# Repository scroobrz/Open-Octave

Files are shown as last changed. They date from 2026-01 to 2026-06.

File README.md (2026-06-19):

<div align="center">
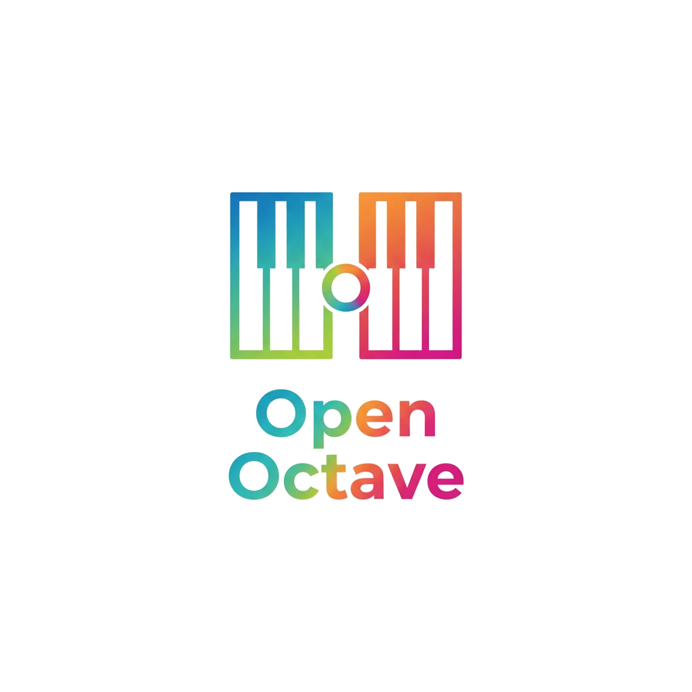
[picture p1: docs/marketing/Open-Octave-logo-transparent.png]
Open Octave Logo
  
</div>

# Open Octave

## Project Overview
**Open Octave** is a modular, robotically enhanced educational piano keyboard system designed to make early-stage piano education more accessible and engaging in the classroom. The physical system consists of connectable keyboard modules controlled by our firmware. The system also provides a teacher-facing frontend which allows them to control the keyboard modules remotely, and a proxy server for software-firmware communication.

**Open Octave's** robotic features, such as light-up keys and a self-playing mechanism, enable unique learning modes aimed at aiding the retention of melodic piano sequences for young learners. Its modularity also encourages less advanced learners to become familiar with the mechanics of piano playing on smaller keyboard modules without being overwhelmed by a full 88-key smart keyboard with all bells and whistles.

**Open Octave** began as an undergraduate robotics project at The University of Edinburgh, and has now been made open course for further development.

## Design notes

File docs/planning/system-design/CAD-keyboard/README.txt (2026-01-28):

MIDI keyboard keys - Casio CTK3000 by Dark_Jumpy on Thingiverse: https://www.thingiverse.com/thing:4328527

Summary:
MIDI keyboard keys designed for Casio CTK3000 but it's possible it also fits other keyboards. If you would like to print the whole octave you have to print:-1 x holding-belt-5 x piano_black_key-2 x type1-piano-white-key-2 x type2-piano-white-key-1 x type3-piano-white-key-1 x type4-piano-white-key-1 x type5-piano-white-keyIf you would like to print the whole octave with the one full white key on any side you have to print:-1 x holding-belt-long-5 x piano_black_key-2 x type1-piano-white-key-2 x type2-piano-white-key-1 x type3-piano-white-key-1 x type4-piano-white-key-1 x type5-piano-white-key-1 x full-piano-white-keyWhen you printed your octave then you have to put your keys in they place in MIDI keyboard and glue to them a holding belt. Next, you have to make holes for the screws in the places where are holes in the MIDI keyboard in that way witch you can screw octave to the keyboard. If you would like to have a nice look of the keys I recommend print them slowly because they have thin walls.If you have any question let me know about it in the comment.

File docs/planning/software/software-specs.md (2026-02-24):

# Open Octave – Demo 2 Architecture & Integration Specification  
**(Alignment Document)**

---

# 1. Demo 2 Scope and Locked Decisions

## 1.1 Objectives

Demo 2 must deliver:

- Replacement of Demo 1 CLI with Software (Node controller + Web UI)
- Firmware-controlled Guided and Teaching logic
- USB Serial as primary communication path
- WiFi WebSocket as optional path
- Clean architecture that scales to Demo 3 (multi-module networking)
- Flexible protocol that avoids rewriting firmware later

**refer controller/server.js

---

## 1.2 Transport Decisions

### Primary (Demo 2)
- USB Serial @ 115200 baud

### Optional (Demo 2)
- ESP32 SoftAP
- WebSocket server on port 81
- Same single-character command format over both transports

### Future (Demo 3)
- Raspberry Pi hosts:
  - WebSocket server
  - SQLite database
  - WiFi Access Point
- ESP32 modules become WebSocket clients

---

# 2. Command & Protocol Architecture

## 2.1 Command Philosophy

- **Single-character commands** → button-like actions
- **Text-based structured responses** → machine-readable state and events
- Same command format across Serial and WebSocket

---

## 2.2 Idempotency Rules

| Command | Behavior |
|---|---|
| Mode change (`m`, `a`, `f`) | Idempotent. No effect if already in that mode. |
| `s` (start) | Ignored if already running. |
| `x` (stop) | Idempotent. Stops immediately. |
| Sequence select | Stops current sequence before switching. |
| Restart | Separate command if needed (not `s`). |

Stop confirmation popup is handled in the UI (default = Yes on Enter).

---

## 2.3 Machine-Readable Responses (Required)

Firmware must emit structured messages prefixed with:

- `ACK` (acknowledge)
- `STATUS`
- `EVT` (event)
- `ERR` (error)

### Examples

```
ACK mode=GUIDED
ACK start=ok seq=3
ACK stop=ok
ERR cmd=start reason=manual_mode
STATUS mode=GUIDED running=1 seq=3 step=4
EVT guided_step key=2 duration=500
EVT correct_press key=2
EVT wrong_press expected=2 got=5
EVT hold_complete key=2
EVT sequence_complete
```

Controller updates state ONLY from these structured messages.

**Backend will do the processing, and esp32 will just send the current event/ack going on

Reason: if using local mirror from microcontroller "sent", false positive communication may occur. we only know command left the controller, but not sure if esp32 received/accepted/actually changed mode. (more robust)

---

## 2.4 Status Query (Locked)

New command: `q`

Firmware response: ```STATUS mode= running=<0|1> seq= step=```

Demo 3 option (not implemented now):
- Periodic heartbeat `HB ...`

---

## 2.5 Sequence List (Machine-Readable)

New command: `L`

Response format: ```SEQ_LIST 0:PingPong|1:OdeToJoy|2:Lullaby|…```

---

# 3. Guided Mode Specification

Firmware fully owns Guided logic.

Software:
- Triggers mode
- Displays state
- Logs events
- Tracks wrong presses for future reports

---

## 3.1 Required Guided Behavior

For each step:

1. Emit: ```EVT guided_step key=K duration=D```
2. LED turns on.
3. If wrong key pressed: ```EVT wrong_press expected=K got=J```
4. On correct press: ```EVT correct_press key=K```
5. Enforce hold duration D: ```EVT hold_complete key=K```
6. Advance step.
7. On completion: ```EVT sequence_complete```

---

## 3.2 Known Limitations (To Improve)

### Repeated Notes Issue
If the same key appears consecutively:
- LED does not visually indicate new step.

Possible solutions:
- LED pulse at step start
- Require release edge before next press
- Brief LED off-on reset

### Hold Visualization
LED remains ON during hold.
Optional:
- Blink or color change when release allowed.

---

# 4. Sequence Management Plan (Two Stages)

---

# Stage 1 – Hardcoded Sequences (Demo 2 Initial)

- Sequences remain in firmware (`firmware_V4_sequences.h`)
- Controller only selects and triggers playback
- No upload protocol required
- SQLite already implemented on server for future compatibility

---

# Stage 2 – Upload Protocol + SQLite (Demo 2 Extension)

## 4.1 Sequence Upload Protocol (Locked: Option A)

Line-based text protocol using newline delimiters.

for now, choose midi files that use ONLY one octave keys to show users can upload midi files and converted into light sequences.

### Begin Upload
```U seq_id=12 name=“OdeToJoy” steps=7```

### Step Lines
```S i=0 k=1 c=00FF00 d=400
S i=1 k=1 c=00FF00 d=400
```

### End Upload
```E seq_id=12```

### Firmware Responses
ACK upload=begin seq_id=12 steps=7
ACK upload=step i=0
…
ACK upload=end seq_id=12 stored=ram
ERR upload=bad_step i=3 reason=invalid_key

---

## 4.2 Expected Upload Time

Serial throughput ≈ 11,520 bytes/sec.

Estimated upload times:

| Steps | Approx Time |
|--------|-------------|
| 16     | ~0.05 sec |
| 64     | ~0.18 sec |
| 128    | ~0.34 sec |
| 256    | ~0.68 sec |

Even with ACK responses, upload remains sub-second for normal sequence sizes.

---

## 4.3 Option B (Future Consideration Only)

Length-prefixed JSON frames.

Pros:
- Self-describing
- Structured

Cons:
- Heavier parser
- Higher firmware risk
- More memory usage

Not selected for Demo 2.

---

# 5. Server-Side Storage Decision (Locked)

We will use **SQLite starting in Demo 2 Stage 2**.

Reason:
- Simple single-file database
- Works on laptop and Raspberry Pi
- Avoids migration later
- Durable and reliable
- Industry-standard lightweight storage

---

## 5.1 SQLite Schema

### Table: sequences
- id INTEGER PRIMARY KEY
- name TEXT
- created_at TEXT
- updated_at TEXT

### Table: sequence_steps
- id INTEGER PRIMARY KEY
- sequence_id INTEGER
- step_order INTEGER
- key_index INTEGER
- color INTEGER
- duration_ms INTEGER

---

## 5.2 State Tracking Storage

- Live device state: In-memory only
- Persist sequences in SQLite
- Optionally persist:
  - Last selected sequence
  - Last known mode

Do NOT write state changes (like every step) to DB.

---

# 6. Proxy-Side State Tracking (Locked)

Old behavior:
- Controller returned `{success:true, cmd:"m"}`

New behavior:
- Controller waits for `ACK`
- Maintains local mirror:
  - mode
  - running
  - current sequence
  - step index

API returns mirror state, not just “cmd sent”.

Reason:
- Transport success ≠ firmware success
- Needed for multi-device future
- Prevents UI desync

---

# 7. MIDI Strategy

## Demo 2
- Pre-convert MIDI offline
- Hardcode sequences

## Demo 3 Direction
- Parse MIDI on server (Node.js)
- Convert to sequence steps
- Store in SQLite
- Upload using Stage 2 protocol

Library candidate:
- `@tonejs/midi`

Still required:
- Pitch mapping rules
- Tempo conversion
- Quantization
- Polyphony handling strategy

---

# 8. Firmware Responsibilities (After Review)

Firmware must add:

- ACK responses for all state-changing commands
- STATUS command (`q`)
- Machine-readable sequence list (`L`)
- Guided mode event emission
- Upload parser (Stage 2)
- Fixed-size RAM buffer for uploaded sequences
- Step validation and limits

Avoid:
- Heavy dynamic memory
- JSON parsing in firmware

---

# 9. Electronics Alignment Required

## 9.1 12-Key Scaling
- Final GPIO mapping
- LED wiring strategy (individual pins vs chained strip)
- I2C reserved pins
- Confirm pull-up strategy

## 9.2 Power
- Servo power budget
- Grounding scheme
- 3.3V logic compatibility

## 9.3 Audio
- Confirm final audio approach before implementing volume control

---

---

# 10. Additional Architectural Considerations & Constraints

This section consolidates important considerations, risks, and alignment notes that were agreed during design discussions but were not yet explicitly written into this document.

---

# 10.1 Logging, Memory Model & Safe Upload Limits 

The firmware uses structured log prefixes (`ACK`, `STATUS`, `EVT`, `ERR`) to support robust software-side state tracking.

## Logging Memory Model

- Logging macros use fixed-size stack buffers (`LOG_BUFFER_SIZE = 128`).
- No persistent log buffering is implemented.
- Logs are streamed directly to Serial and WebSocket.
- Machine-readable prefixes do **not** significantly increase RAM usage.
- Avoid heavy dynamic `String` usage inside frequent execution paths.
- No JSON parsing will be implemented in firmware.

This keeps memory deterministic and avoids heap fragmentation.

---

## Upload Memory Strategy (Safe Maximum Based on `SequenceStep` Size)

Uploaded sequences will be stored in RAM only.

No dynamic heap allocation will be used for upload storage.

Instead, firmware will use a fixed-size static buffer: ```SequenceStep uploadedSteps[MAX_UPLOADED_STEPS];```

### SequenceStep Memory Size (proposed)

```cpp
struct SequenceStep {
uint8_t keyIndex;   // 1 byte
uint32_t color;     // 4 bytes
uint16_t duration;  // 2 bytes
};
```

Estimated raw size ≈ 7 bytes  
Aligned size (typical 32-bit alignment) ≈ 8 bytes per step.

### Safe Maximum Step Count

The safe maximum will be calculated based on:

- Available free heap after firmware initialisation
- Worst-case stack usage
- Logging buffer usage
- WiFi + WebSocket memory overhead

The buffer size will be selected conservatively to:

- Avoid memory exhaustion
- Avoid heap fragmentation
- Maintain stable servo + LED timing

Example estimation (for reference only):

| Steps | Approx RAM Usage |
|---|---|
| 128 | ~1 KB |
| 256 | ~2 KB |
| 512 | ~4 KB |

Final `MAX_UPLOADED_STEPS` will be locked after measuring actual free heap on ESP32 during runtime.

---

## Firmware Constraints for Electronics Team

Electronics team should expect:

- Upload storage is RAM-only (not flash).
- Maximum uploaded sequence length is fixed and enforced.
- Oversized uploads will return: ```ERR upload=too_many_steps max=```

- No dynamic heap expansion for upload.
- Deterministic memory usage is prioritised over flexibility.

This ensures:
- Stable real-time performance.
- No unexpected servo timing jitter.
- No runtime crashes due to heap fragmentation.

---

## Design Principle 

Firmware memory usage must remain:

- Deterministic
- Bounded
- Real-time safe

Flexibility (e.g., unlimited upload length) is intentionally sacrificed to maintain system stability.

---

# 10.2 Command Design Rule (Locked Principle)

To prevent protocol drift in Demo 3:

- **Single-character commands** are reserved for button-like control actions.
- **Text-based messages** are reserved for structured data transfer (upload, state, events).

---

# 10.3 Stop Confirmation – Explicit Responsibility Split

- Firmware stops immediately upon receiving `x`. (separate command from current `stop sequence`)
- Confirmation logic is handled entirely in the UI.
- UI displays confirmation modal.
- Pressing Enter defaults to "Yes". (prevent double clicking)

Firmware might not implement delayed stop logic.

---

# 10.4 Guided Mode – Open Discussion Flags

The following items require joint firmware + UX + electronics alignment before final locking:

## Repeated Notes Handling

Problem:
- Consecutive identical key steps do not visually indicate a new required press.

Options:
- LED pulse at each new step.
- Require release edge detection before accepting next press.
- Brief LED off-on reset between steps.

---

## Hold Duration Visualization

Current:
- LED remains ON during hold.

Possible improvements:
- LED blinking while hold is active.
- LED color change when release allowed.
- Progress-style visual indicator.

Requires UX discussion.

---

# 10.5 Sequence Upload – Memory Limits & ACK Strategy

## Upload Storage Decision

- Uploaded sequences are stored in RAM only.
- Not persisted in flash.
- Maximum step limit must be defined (e.g., MAX_UPLOADED_STEPS).
- Upload exceeding limit must return: ```ERR upload=too_many_steps max=```

## ACK Strategy (Low-Risk Compromise)

To balance reliability and traffic:

- `ACK upload=begin`
- Optional periodic ACK (every N steps)
- `ACK upload=end`

Per-step ACK is allowed but increases traffic.

Serial throughput remains sub-second for normal sizes.

---

# 10.6 Database Design Assumptions

SQLite is selected starting from Demo 2 Stage 2.

## Assumptions

- Controller is the single writer.
- No concurrent external DB writers.
- Sequences are low-frequency writes.
- Runtime state (step changes) is NOT written to DB.

## Risk Control

- Use transactions when inserting sequences + steps.
- Keep live state mirror in memory.
- Persist only low-frequency configuration data.

---

# 10.7 MIDI Parsing Responsibility (Explicit Separation)

Firmware will NOT parse MIDI.

All MIDI processing will occur on the server side:

1. Parse MIDI file.
2. Convert to internal step structure.
3. Apply:
 - Pitch mapping rules.
 - Tempo conversion.
 - Quantization.
 - Polyphony strategy.
4. Store in SQLite.
5. Upload to firmware via Stage 2 protocol.

This keeps firmware lightweight and real-time safe.

---

# 10.8 Demo 3 Networking – High-Level Alignment Notes

Future architecture direction:

- One Raspberry Pi controls multiple ESP32 modules.
- Each module must have a device identifier.
- Controller must track state per device.
- Commands must be routed per module.
- Upload protocol must support device targeting.

Implication:
Protocol design today must remain extensible for device addressing.

---

# 11. Upload Protocol – Future Option B (Documented for Consideration)

Alternative approach:
Length-prefixed JSON frame.

Pros:
- Self-describing.
- Easier for server-side logic.

Cons:
- Larger memory footprint.
- More parsing complexity.
- Higher firmware risk.

Not selected for Demo 2.

---

# 11.1 Architectural Risk Summary

| Risk | Mitigation |
|---|---|
| UI state desync | ACK/STATUS-based mirror |
| Upload overflow | Fixed-size RAM buffer |
| Serial corruption | Line-delimited protocol |
| Firmware memory pressure | Avoid JSON + dynamic allocation |
| Demo 3 rewrite risk | Single-char + text separation rule |
| Multi-module scaling | Device-aware protocol planning |
s

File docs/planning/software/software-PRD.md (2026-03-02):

# Open Octave – Software Product Requirements Document (PRD)
## Demo 2 (with Stage 2 Upload) – Final Integration Version

---

# 1. Overview

## 1.1 Purpose

This PRD defines the complete software requirements for Open Octave Demo 2.

The software must:

- Communicate reliably with `firmware_v4`
- Support USB Serial (primary) and WebSocket (optional)
- Maintain a controller-side state mirror
- Store sequences in SQLite
- Upload exactly ONE active sequence to firmware RAM
- Remain low-risk and deterministic
- Be extensible for Demo 3

---

# 2. Firmware Contract & Version Requirement

## 2.1 Purpose

Software depends on specific firmware capabilities.  
To avoid integration ambiguity, firmware must conform to this contract.

---

## 2.2 Minimum Required Firmware

Firmware must emit at startup:

```
FIRMWARE_VERSION=<version>
FIRMWARE_CONTRACT=1.0
```

If `FIRMWARE_CONTRACT=1.0` is not present, software must:

- Disable structured state tracking
- Disable upload functionality
- Fall back to limited command relay mode

---

## 2.3 Firmware Contract v1.0 Requirements

Firmware must implement:

1. Newline-delimited command parsing
2. Prefixed logs (`ACK`, `STATUS`, `EVT`, `ERR`)
3. Emit `STATUS` after every `ACK`
4. Guided mode event logs
5. Stage 2 upload protocol (`U/S/E`)
6. Single active uploaded sequence in RAM
7. WebSocket payload null-termination safety
8. FREE_HEAP logging at boot and upload begin

---

# 3. System Architecture

## 3.1 Components

- Node.js backend (controller)
- SQLite database
- Browser-based UI
- ESP32 firmware_v4

---

## 3.2 Transport

### Primary
USB Serial @ 115200 baud

### Optional
WebSocket (ESP32 SoftAP)

Both transports use identical newline-delimited protocol.

---

# 4. Communication Protocol

## 4.1 Command Framing (Locked)

All commands MUST end with newline.

Examples:

```
m\n
s\n
U i=3 n=Ode-To-Joy s=16\n
```

No newline → command invalid.

---

## 4.2 Supported Single-Character Commands (Demo 2)

| Command | Meaning |
|---|---|
| m | Manual mode |
| a | Guided mode |
| f | Teaching mode |
| s | Start sequence |
| x | Stop sequence |
| l | Print current sequence |
| t | Test LEDs |
| u | Test servos |
| g | Toggle CSV test log |
| h / ? | Help |

Software MUST NOT send unsupported commands.

---

# 5. Machine-Readable Log Protocol

Software parses ONLY lines starting with:

- `ACK `
- `STATUS `
- `EVT `
- `ERR `

All other logs ignored.

---

## 5.1 ACK

Example:

```
ACK cmd=m ok=1
```

After every ACK, firmware must emit STATUS.

---

## 5.2 STATUS

```
STATUS mode=GUIDED running=1 seq=2 step=5
```

Fields:

- mode: MANUAL | GUIDED | TEACHING
- running: 0 or 1
- seq: active sequence id/index
- step: current step index or -1

Controller updates state mirror from STATUS only.

---

## 5.3 EVT

Guided events:

```
EVT guided_step k=2 d=500
EVT correct_press k=2
EVT wrong_press e=2 g=5
EVT hold_complete k=2
EVT sequence_complete
```

Used for UI feedback and future analytics.

---

## 5.4 ERR

```
ERR cmd=s reason=manual_mode
```

Software must not assume state change on ERR.

---

# 6. Controller State Model

Software maintains in-memory state:

```
{
  transport: "serial" | "ws",
  connected: boolean,
  mode: "MANUAL" | "GUIDED" | "TEACHING",
  running: boolean,
  seq: number,
  step: number,
  uploading: boolean,
  uploadSeqId: number | null,
  uploadProgress: number | null,
  lastError: string | null
}
```

State is derived only from prefixed logs.

---

# 7. Database (Required for Stage 2)

SQLite required.

## 7.1 Tables

### sequences
- id INTEGER PRIMARY KEY
- name TEXT
- created_at TEXT
- updated_at TEXT

### sequence_steps
- id INTEGER PRIMARY KEY
- sequence_id INTEGER
- step_order INTEGER
- key_index INTEGER
- color INTEGER
- duration_ms INTEGER

---

## 7.2 Rules

- Database is source of truth.
- Firmware stores only one active sequence in RAM.
- Switching sequence → upload required.
- Runtime step updates are NOT stored in DB.

---

# 8. Stage 2 Upload Protocol

## 8.1 Format

Begin:

```
U i=<seqId> n=<name> s=<stepCount>
```

Step:

```
S i=<index> k=<keyIndex> c=<RRGGBB> d=<durationMs>
```

End:

```
E i=<seqId>
```

All lines newline-delimited.

---

## 8.2 Upload Rules

- One active uploaded sequence only.
- Uploaded sequence becomes active automatically.
- Oversized uploads rejected safely.
- Color format: exactly 6 hex characters.
- Name normalized (spaces → `-`).

---

## 8.3 Upload Flow

1. Send U
2. Wait for `ACK upload=begin`
3. Send S lines
4. Send E
5. Wait for `ACK upload=end`
6. Wait for `STATUS`

---

# 9. RAM Strategy

Firmware:

- Uses fixed buffer for uploaded steps.
- Rejects oversized upload.
- Logs free heap at:
  - Boot
  - Upload begin

Example log:

```
FREE_HEAP=238944
```

Software respects firmware upload rejection.

---

# 10. Error Handling

Software must handle:

- Missing ACK
- ERR responses
- Transport disconnect
- Partial upload failure
- Timeout during upload

Upload must abort cleanly.

---

# 11. Transport Handling

## 11.1 Serial

- Auto-reconnect
- Line-based parsing
- Primary demo path

## 11.2 WebSocket

- Same protocol
- Optional path
- Null-terminated payload parsing required in firmware

---

# 12. CSV Test Log Compatibility

CSV output must not use prefixed keywords.

Controller ignores non-prefixed lines.

---

# 13. Non-Goals (Demo 2)

Not required:

- Multi-device support
- Device IDs
- Heartbeat
- JSON protocol
- Persistent firmware storage
- Multiple uploaded sequences

---

# 14. Demo 3 Future Extensions (Not Required Now)

- Multi-device routing
- Device ID prefix
- Periodic heartbeat
- Cloud sync
- Sequence editor UI

---

# 15. Low-Risk Principles

- Line-based protocol only
- No JSON over firmware link
- Prefixed structured logs
- Deterministic RAM usage
- Single active uploaded sequence
- Database as source of truth
- STATUS after every ACK

---

# Final Requirement

Software generated from this PRD must:

1. Send newline-terminated commands.
2. Parse only prefixed logs.
3. Maintain local state mirror from STATUS.
4. Use SQLite for sequence storage.
5. Upload exactly one active sequence.
6. Treat Serial as primary transport.
7. Fail gracefully if firmware contract not met.

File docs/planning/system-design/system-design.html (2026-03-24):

# Open Octave — System Design

## 1. Current Architecture (Single Module)

## 2. Target Architecture (Production / Multi-Module)

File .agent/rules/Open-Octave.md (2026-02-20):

---
trigger: always_on
---

# Open Octave Project

## Overview
**Open Octave** is a modular, robotically enhanced educational keyboard system designed to enhance piano learning in classrooms. The product will consist of octave-sized keyboard modules which can function independently or connect together to form larger keyboard components. Each module will be digitally and robotically augmented to facilitate accessible learning, with light-up keys and a self-pressing mechanism to effectively show beginners how to play melodies.

## The System
Open Octave reimagines the keyboard as a scalable system. Our modular hardware allows schools to start small and grow their inventory as budgets allow, while our robotic enhancements ensure the system is truly accessible to beginner learners - and our accompanying software makes the system manageable within a large classroom setting.

All Open Octave modules will support three modes:
1. Piano Mode, where the keyboard simply functions like a regular piano.
2. Guided Mode, where the keyboard lights up while being played to provide sequential fingering cues; the user plays along with the cues, and the keyboard waits for each key to be pressed before lighting up the next one.
3. Teaching Mode, where the keys press themselves down to physically demonstrate how to play a melody and key lights up with different colours indicating which finger should be used to press which key.

## Tasks
Open Octave is decomposed into three subsystems which require different skills and can be worked on in parallel by separate teams throughout the project: the hardware & mechanics, the firmware & electronics, and the software application. At a high level, the hardware & mechanics team is responsible for the physical manufacturing of the keys and interlocking keyboard frames, the firmware & electronics team is responsible for the electronic architecture and corresponding embedded programming, and the software team is responsible for developing the application which remotely controls the keyboards.

### Key Milestones
The project roadmap is centered around three key milestones:

**Demo 1 (11/2/2026): Robotic Fundamentals**
The goal of Demo 1 is to demonstrate the robotic aspect of Open Octave. We aim to have a few keys (at least two) connected to a microcontroller with speaker output, which can demonstrate the following basic robotic functions:
1. Pressing of keys triggering instantaneous audio output.
2. Robotic autopressing and lighting-up of keys; these functions should work in tandem, i.e should happen at the same time.
3. Automated playing of a basic, hardcoded melody using the autopressing and light-up functionality.

**Demo 2 (4/3/2026): Full Octave and Operating Modes**
The goal of Demo 2 is to demonstrate a framed 12-key octave which is able to showcase the basic functions of all three modes of operation. That is, the keyboard should demonstrate the following functionalities:
1. For Piano Mode: The keyboard should be fully functional as a basic keyboard, where a user can press keys and play music without any robotic assistance.
2. For Guided Mode: The keyboard should be able make keys light up in a specific sequence based on one or two preset hardcoded songs; the keyboard should light up one key at a time and wait until each key has been pressed before lighting up the next one; the light colours should correctly correspond to which fingers should be used to play each note.
3. For Teaching Mode: The keyboard should be able to automatically play a preset, hardcoded song in real time, utilising the auto-press and light-up functions to demonstrate how to play this song to the user.

**Demo 3 (25/3/2026): Modularity and Networking**
The goal of Demo 3 is to demonstrate the full vision of Open Octave: multiple keyboard modules physically connected and digitally networked to create a scalable infrastructure for learning. We aim to demonstrate the following:
1. Have two independently functional keyboard modules.
2. Have the keyboard modules physically interlock to form a fully-functional two-octave keyboard.
3. Have the larger two-octave keyboard showcase more complex songs than what is already possible on a single octave.
4. Have an external software application which can be used to remotely control the keyboard modules (on/off, volume, etc.), activate functions, configure modes, see module connection information, and maybe upload and select songs as MIDI files, and get feedback based on the students’ playing.

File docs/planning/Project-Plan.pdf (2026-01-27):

Group Number: 21 | Project Plan

## Product: Open Octave

Team: Team OOP

Abstract

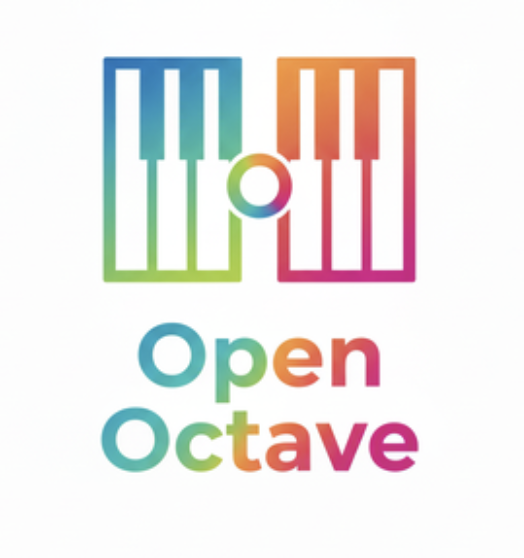
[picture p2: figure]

Open Octave is a modular, robotically enhanced educational keyboard system designed to enhance piano learning in schools. The product will consist of octave-sized keyboard modules which can function independently or connect together to form larger keyboard components. Each module will be digitally and robotically augmented to facilitate accessible learning, with light-up keys and a self-pressing mechanism to effectively show beginners how to play. Overall, our system will be composed of three main components: Hardware & Mechanics which will be the specialised keys and frame, Electronics & Firmware which will be responsible for controlling and connecting hardware components in a meaningful way, and a Software Application which teachers can use to remotely configure and control a network of the keyboard modules. Throughout this project, we will need to successfully develop systems for motorised auto-press control, light signal processing, MIDI processing, mode control, module interlocking and connectivity, remote control, multi-PCB communication, and device networking.

### 1. Pitch

Access to modern music education technology within the public school system has long been hindered by budget constraints (House of Lords Library, 2023). Modern, technologically-enhanced equipment like smart keyboards has struggled to become a permanent fixture of underfunded music departments, impeding the accessibility of learning an instrument within schools.

We want to make smart keyboards completely accessible in the classroom with a flexible, approachable, and budget-friendly educational keyboard tool. Our product, Open Octave, is unique in three ways:

1. It leverages robotic actuation (with light-up keys and automatic self-playing) to visually aid students in their learning.
2. It employs a modular design which allows the instrument to grow with the user and allows schools to easily scale their hardware in line with the needs of both students and budget considerations.
3. It comes with an external software application which

allows teachers to remotely manage the system of keyboard modules.

All Open Octave modules will support three modes:

1. Piano Mode, where the keyboard simply functions like a regular piano.
2. Guided Mode, where the keyboard lights up while being played to provide sequential fingering cues; the user plays along with the cues
3. Teaching Mode, where the keys press themselves down to physically demonstrate how to play a melody and key lights up with different colours indicating which finger should be used to press which key. Wu et al. demonstrate the positive effect of visual cues on learning performance for rhythmic tasks (Wu et al., 2022), further supporting our smart visual assistance proposal.

While each octave-sized keyboard module will be fully functional on its own, students should not be expected to limit themselves to just twelve keys forever. As students’ abilities grow, our modular design will allow them to join multiple octaves together to create larger keyboard components - creating a smart keyboard which grows alongside the ability of students. This also ensures that the schools do not incur any unnecessary costs, only upgrading equipment for the students who need it.

Open Octave reimagines the keyboard as a scalable system. Our modular hardware allows schools to start small and grow their inventory as budgets allow, while our robotic enhancements ensure the system is truly accessible to beginner learners - and our accompanying software makes the system manageable within a large classroom setting. With this project, we hope to form part of a sustainable solution for music education in schools.

### 2. The Team

Ao Zhang is a Computer Science and Artificial Intelligence student with a background in Java and C programming languages. He has got relative experience with LEGO robots and TurtleBots thus willing to work with hardware, but he is also happy to take care of the firmware development part on top of this. He has developed his management skills working as a senior leader of the infPALS scheme.

Laurie Joslin After taking research experience in a startup and academic environment, he has strong experience in

Software Engineering and Data Science. This is coupled with a strong soft skill set in public speaking, team collaboration and project management. Laurie is excited to further his skill in project management by organising roadmaps and sprints but lacks direct hardware experience, albeit is keen to learn more. He is happy to work with firmware and software development.

Ahmad Akasha is an Electronics and Computer Science student with experience in digital system design, analogue circuits, embedded programming, and PCB design. He is comfortable working across the hardware–firmware boundary, with particular strengths in C, Verilog, and microcontroller-based systems. For this project, Ahmad will focus on actuator control, electronics integration, and reliable communication between embedded hardware and higher-level firmware. He has prior engineering internship experience and is confident coordinating technical work across sub-teams during development and testing.

Shuoshuo Wang A computer science student with a background in Python and Java programming languages, he prefers to contribute to the software-related aspects of projects. He hopes to participate in software development tasks related to the overall system functionality and coordinate with the operation of other components within the system. Through the SDP project, he hopes to further accumulate practical software engineering project experience and improve his development and communication skills in a collaborative team environment.

Robin Campbell-Parker Software Engineering student with a proficiency in Java and comfortable with Python and C. His professional experience is grounded in the AI space, but also covers software testing and evaluation. He is excited to work as part of a large team and gain experience with new technologies in a multifaceted project setting, while also utilising his current skills to help out wherever needed.

Ning Liu Computer science student with a good understanding of Java, Python and C programming languages. He is passionate about further developing his technical skills and problem-solving abilities and will assist building the hardware throughout the project.

Alvin Bong Computer Science student with interest in Artificial Intelligence and Software Engineering. He has experience with Data Science and ML projects focused on the finance sector. He is also comfortable with backend development with Java, Spring Boot and Docker and frontend development mainly with React. Outside of technical CSbased knowledge, he has participated in case competitions; he is usually tasked with training models and building dashboards. Alvin is eager to expand his skill sets and contribute to the software side of the project.

Tommy Bardsley Computer Science student with experience mostly in OOP-centred programming languages like Java, C#, Python and a working understanding of Rust. He also has a basic grasp of working with databases, mostly using SQL. Tommy is interested in the security and networking side of Computer science and looks forward to learning new skills and applying his pre-existing skills to develop the firmware in this project.

### 3. Users

The primary users of our system are beginner piano learners, particularly children and early-stage learners who are being introduced to keyboard instruments and musical theory for the first time. Learning piano at an early stage can often be frustrating, as beginners are expected to translate abstract information such as sheet music or note names into correct physical movements on a keyboard. Our system is designed to support these learners by providing a holistic picture, instantiating sheet music and music theory through visual and physical demonstration.

Consider a beginner learner, Alex, who has just started learning piano at school and is eager to learn as much as possible. Alex does not yet read sheet music and struggles to remember which keys to press when following verbal or visual instructions. With Open Octave, Alex’s teacher can select a song for him to learn. The system then physically demonstrates the melody in Teaching Mode by actuating the keys in sequence whilst simultaneously illuminating them. Alex can watch and listen as the keyboard plays the tune, observing both the order and timing of key presses. After this demonstration, Alex attempts to reproduce the melody in Guided Mode using the illuminated keys as guidance. When Alex feels confident enough, he can use Piano Mode to practise independently of any robotic assistance. This interaction allows Alex to learn through observation and repetition, closely resembling how a teacher might demonstrate a passage during a lesson.

Several contextual constraints shape the product design for this primary user group. The system must be safe to use around children, as it includes moving mechanical components. Actuation forces are therefore limited, and the system is intended to operate at moderate speeds suitable for beginner-level melodies. Simplicity is also essential: learners should be able to use the system without navigating complex menus or relying on external devices. As such, a lot of the configuration is abstracted away to the teacher via an external application - whilst the core components required for learning are easy to use and understand for the student.

The secondary group of users includes music teachers and educators, who are responsible for administration and setup of the Open Octave system. Often-time in music lessons, teachers struggle with being able to help all students learn. This is because students may be playing independently and most likely will have different progression rates. In this case, Open Octave provides a interface showing if a student has successfully played a song they have been guided through. This transforms music lessons, with teachers now able to give specialised support to struggling students whilst also providing competent students with another Open Octave module, extending both their knowledge and learning. This facilitation of targeted learning is an important consideration in the design of Open Octave.

While the needs of these user groups largely align, there are trade-offs which we have had to consider in our design. Our design prioritises an accessible default interaction for beginners, restricting configuration features and some controls to the network interface accessed by teachers. For a musical education use case, we decided this was the best approach. However it can be acknowledged that an abstraction of control away from individual students could limit students of a higher musical calibre, who perhaps would want to select their own songs to learn to play instead of being limited by the teacher’s choice for the class.

Overall, the system is designed to support beginner piano learning by grounding musical instruction in physical action rather than abstract representation. By physically demonstrating melodies and enabling imitation-based learning, the system addresses a genuine educational need that cannot be fulfilled by purely software-based applications. This user-centred perspective provides a strong foundation for deriving detailed user stories and system requirements in later stages of the project.

### 4. Impact

We envision this system as a proprietary product which could be sold or rented out to educational institutions. We would expect educational institutions to buy (or rent) sets of our modules for their classrooms, allowing them to address the needs of large groups of students trying to learn to play the piano at once. As the needs of these institutions scale, so too would their consumption of the product; for example, when a large proportion of students get good enough to work on multiple connected modules at once, the school might want to purchase more to accommodate this.

This addresses what is currently the biggest barrier to entry for music education within schools: the high cost of quality instruments and educational tools. Research into the current state of music education in the United Kingdom found that the mean yearly budget for music departments in state schools was just £1,865 (Underhill, 2022). This highlights a stark contrast between the offerings of modern technology and the reality of what schools can afford. With even the "budget-friendly" smart keyboards costing several hundred pounds (Welter, 2026), the vision of a classroom where every student has their own instrument is a financial impossibility. Our system bridges this gap by offering a modular, scalable alternative to modern smart keyboards which can be tailored to the financial needs of a school and the abilities of its students.

Another issue we are tackling is the relative inaccessibility of current smart keyboards. A student who has never touched an instrument does not need a full 88-key smart keyboard with all the bells and whistles; they need a simple educational tool which is fitted to their needs and can scale with their ability. This disconnect is especially pertinent for students with intellectual disabilities; Braun et al. highlights the importance of "personalized, adaptable, and customizable technologies" to accommodate those with such disabilities (Braun et al., 2025). We address this divide by incorporating simple visual aids without overcomplicating anything, and offloading complicated controls to the teacher via software.

By creating this new infrastructure for learning the piano within schools, we envision the following wider social implications to be relevant:

- Positive social implications:
1. Equal Opportunities: Our system makes highquality instruments affordable for every school, helping to level the playing field for students at state schools vs those at independent/public institutions.
2. Sustainable Scaling: Traditional classroom keyboards are often "all-or-nothing" investments that either lack or contain too many features for a classroom setting. Our modular product provides a flexible, long-term asset which encourages departments to commit to piano education with less worries about budget, space constraints, and scalability.
3. Inclusive Classroom Participation: Following the findings of Braun et al., the robotic elements provide the "personalized and adaptable" technology necessary for bridging the gap for students with intellectual disabilities. In a classroom setting, this ensures that these students are not sidelined but can participate alongside their peers in a meaningful way.
- Potential negative social implications:
1. Surface-Level Learning: While visual cues improve immediate performance, research suggests these gains can sometimes disappear once the aids are removed (Emond & Schoppek, 2026). This raises concerns over creating a gamified classroom environment where students focus on reactive light-matching rather than internalising music theory. Over-reliance on simplified visual cues could hinder students’ fundamental musical comprehension, leaving them unable to perform independently.
2. Visible Talent Hierarchy: Our modular design could risk creating a clear visual hierarchy, where a student’s ability is publicly reflected by the number of octaves they are playing on, where such differences would be less obvious with fullsized keyboards.

To address the concerns outlined above, our design intentionally places teachers at the centre of the learning experience, empowering them to selectively toggle visual aids and robotic assistance based on the educational needs of each student. Also, we would encourage teachers to set up classroom environments with a greater focus on collaboration and inclusive learning, as opposed to more competitive environments - ensuring that students don’t end up directly ranked by ability.

### 5. Outcomes

Our first primary outcome is to ensure our system can provide accurate sound feedback when different keys are being pressed. In musical education, it is crucial for kids to practice on well-tuned pianos so that they can train themselves better on sensing the pitch changes (Liberty Park Music, 2024). As a result, our goal is to develop an accurate sound processing program that outputs sound to headphones and/or a speaker at the correct pitch when a key is being pressed down. One of our main impacts is to make musical and piano learning more accessible to the wider public. Providing accurate sound feedback ensures that more kids have a higher quality learning experience. This will make early music education more accessible, enabling all school children to gain a basic understanding of basic music theory rather than just those whose families can afford a real piano or an 88-key keyboard. To test for this, we will use a digital tuner, which measures how accurate the input sound is compared to the pitch of the actual note. By checking the sound produced by the system when each key is pressed, we can measure how accurate our sound feedback is.

Another primary outcome is the implementation of the two teaching-based modes of operation: Teaching Mode and Guided Mode. A key requirement of the project is that both these modes reflect the input song (in MIDI format) accurately. The aim is to help kids learn how to play a song using Open Octave in an interactive and interesting way. For both of these modes, we will measure our efficacy by manually taking note of the sequence of key presses that’s needed to play the song, then when the device starts to press and/or light up the keys in sequence, we can check if the sequence matches our expectations. We also must ensure that these modes effectively convey fingering information via the light colours, meaning each colour will correspond to a specific finger and so when a key lights up in a certain colour it tells the student to use that finger to press the key. There is no need to verify the LED-fingering relation because, for this project, the fingering of the songs will be hard-coded either by the teacher or us as developers. Given the scope of the SDP project, we thought the decision to hard-code LEDs for fingerings makes sense rather than spending resources writing a complex algorithm to do this for us. This algorithm is a tertiary outcome, an extension to our project.

Another primary outcome is the modularity and interconnection functionality. In the Impact section, we stated that to make modern music education technology more accessible, we are going to modularise our product so that more kids can use our device with schools spending less money. Then, when the kids become more familiar with playing the piano or keyboard, their teacher can connect a few of our modules to form a complete keyboard. This is why modularity is key to our product. We can measure this by testing if the interconnection functionality works, so by connecting two Open Octave modules and seeing if they function as a whole (one module acting as an octave lower than the other) and if the combined keyboard fulfils the first two primary outcomes.

Our final primary outcome is device networking and a simple software solution. We want to control Open Octave modules through a local area network (LAN) in order for teachers to connect to the modules, edit their configurations and choose the modes each module will be on. This will allow for an ideal use case in the classroom. A teacher should be able to easily use a simple GUI application or website that we create that can handle networking to each Open Octave module. This would be conducive to successful music lesson planning and execution. We can test this through extensive user testing, where we will have a software application for people to use. If they are happy with this application being functional and intuitive, we will have fulfilled this final primary outcome.

Upon the completion of our primary goals, we will be focusing on our secondary goals. Our first secondary goal is to allow teachers to import new songs as MIDI files, which will allow students to learn songs beyond what is hardcoded into the devices. We will validate this by checking if the three primary goals work for the imported songs. Another secondary goal is to allow teachers to see information about students’ playing via the app, allowing them to review and give feedback on what each student is doing from one place.

### 6. Tasks

Open Octave is decomposed into three subsystems that require different skills and can be worked on in parallel by separate teams throughout the project: the hardware & mechanics, the firmware & electronics, and the software application. Our rough plan for how specific tasks and personnel will be divided between these teams is shown in Figure 1, and the project timeline for each team is shown as a Gantt chart in Figure 2. While these subsystems are designed to be separate and somewhat independent, team dependencies will grow stronger as the project progresses. For this reason, we expect the teams to be flexible, with multiple people ready to move between and work across teams if needed.

At a high level, the hardware team is responsible for the physical manufacturing of the keys and interlocking keyboard frames, the firmware team is responsible for the development of the microcontroller and the overall electronic architecture of the system, and the software team is responsible for developing the application which remotely controls the keyboards.

The ordering of work is planned based on team dependencies. Firmware cannot be meaningfully integrated until keys produce reliable signals. Software cannot be meaningfully built until firmware exposes controllable behaviours such as mode switching and song triggering. The frame must be designed early with modularity in mind, even before networking is implemented at a later stage. This dependency-driven structure explains why, as shown in Figure 2, software work only begins after Demo 1 - with the software team working instead on firmware in the lead up to Demo 1. Firmware team members will move to the software team after Demo 1 and leverage their understanding of the firmware (while also working closely with the remaining firmware team) to define communication protocols and distributed control mechanisms.

Beyond constructing the system, certain team members will also undertake project management and coordination work. Robin will lead overall project coordination and management of the central project GitHub repository, while Ao will keep track of task completion and ensure goals are being met. Ahmad will be in charge of the firmware & electronics team, leveraging his unique understanding of low-level systems to delegate and coordinate work effectively.

User-facing work will also need to be completed; Laurie will take the lead on preparation of demonstrations and presentations for each demo day, while Alvin will lead the poster design and preparation of marketing materials for the industry showcase. Following Demo 2 and the corresponding user feedback, all project team members will ideate together to ensure synchronisation moving forward.

Throughout the project, we expect firmware & electronics development to be the most time-consuming task, although the scope of this work will change over time. In the early weeks, the primary tasks will focus on hardware-firmware development and integration, but as time goes effort will shift to firmware-software development and integration. Overall, we expect roughly 50% of project effort to be concentrated on firmware & electronics, with the remaining work split evenly between hardware and software.

Throughout these teams, tasks, and subsystems, we plan to delegate work according to specific team members’ competencies and availabilities. For example, Alvin is primarily competent in software development and will also be periodically away from Edinburgh, so he will start on the software side of things as early as possible to accommodate both his skillset and his remote work requirements.

Task prioritisation is based on our presentation goals for each demo day, with each demo acting as proof of a subset of core system functionalities.

Demo 1 (11/2/2026): Robotic Fundamentals

The goal of Demo 1 is to demonstrate the robotic aspect of Open Octave. We aim to have a few keys (at least two) connected to a microcontroller with speaker output, which can demonstrate the following basic robotic functions:

1. Pressing of keys triggering instantaneous audio output.
2. Robotic autopressing and lighting-up of keys; these functions should work in tandem, i.e should happen at the same time.
3. Automated playing of a basic, hardcoded melody using the autopressing and light-up functionality.

Our priority leading up to this demo is to validate and showcase the core mechanical functionality of our system, which will lay the groundwork for all remaining development.

Demo 2 (4/3/2026): Full Octave and Operating Modes

The goal of Demo 2 is to demonstrate a framed 12-key octave which is able to showcase all three modes of operation. That is, the keyboard should demonstrate the following functionalities:

1. Piano Mode: The keyboard should be fully functional as a basic keyboard, where a user can press keys and play music without any robotic assistance.
2. Guided Mode: The keyboard should be able make keys light up in a specific sequence based on one or two preset hardcoded songs; the keyboard should light up one key at a time and wait until each key has been pressed before lighting up the next one; the light colours should correctly correspond to which fingers should be used to play each note.
3. Teaching Mode: The keyboard should be able to automatically play a preset, hardcoded song in real time, utilising the auto-press and light-up functions to demonstrate how to play this song to the user.
4. The keyboard should be able to communicate with a computer via USB to switch between modes and activate functions.

Since Demo 2 is for user-testing and feedback, we have designed the Minimum Viable Product for this demo based on the feedback we want to obtain from users. We primarily want to ascertain whether the educational aspects of our system are actually helpful to complete beginners trying to learn how to play the keyboard.

Demo 3 (25/3/2026): Modularity and Networking

The goal of Demo 3 is to demonstrate the full vision of Open Octave: multiple keyboard modules physically connected and digitally networked to create a scalable infrastructure for learning. We aim to demonstrate the following:

1. Have two independently functional keyboard modules.
2. Have the keyboard modules physically interlock to form a fully-functional two-octave keyboard.
3. Have the larger two-octave keyboard showcase more complex songs than what is already possible on a single octave.

4. Have an external software application which can be used to remotely control the keyboard modules (on/off, volume, etc.), activate functions, configure modes, see module connection information, and maybe upload and select songs as MIDI files, and get feedback based on the students’ output.

Our goal for Demo 3 (Industry Day) is, of course, to have a fully functional system which clearly demonstrates the utility and novelty of our product. If possible, we hope to get feedback from real music educators and try to ascertain the real-world viability of our system.

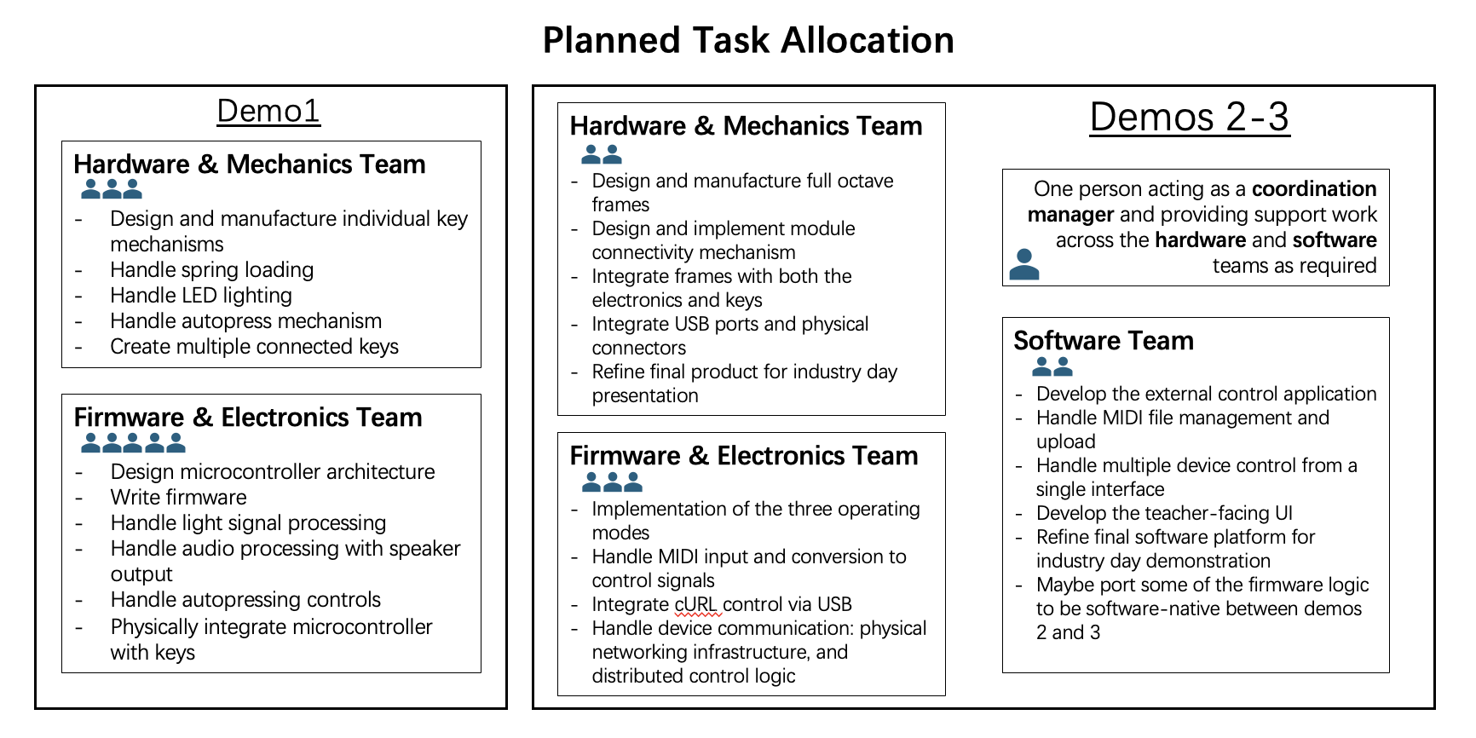
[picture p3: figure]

Figure 1. Task allocation across teams and subsystems

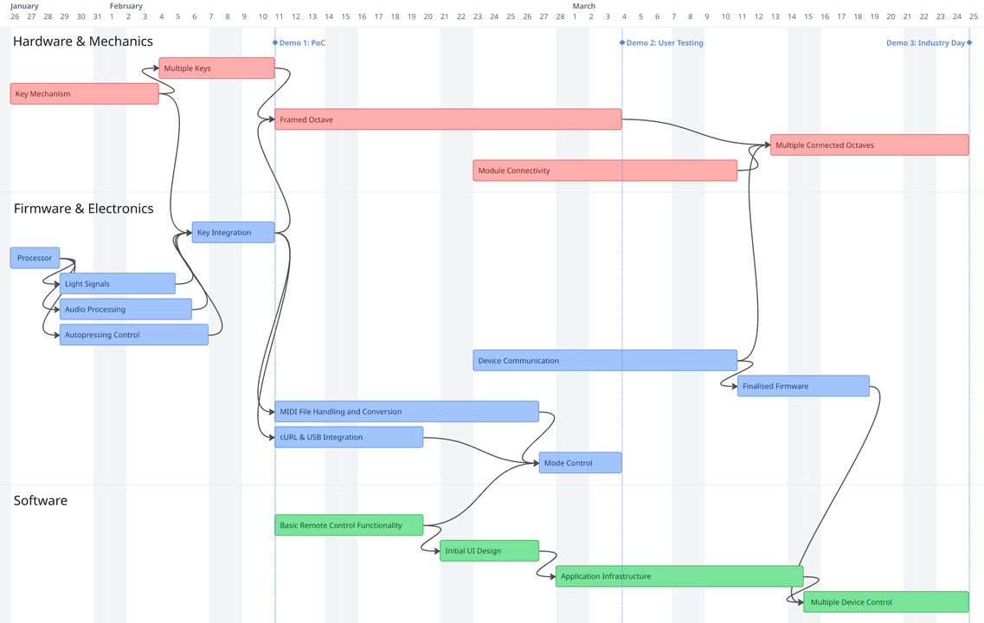
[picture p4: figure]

Figure 2. Gantt chart showing high-level task ordering and dependencies

### 7. Risks

Risk | Likelihood | Impact | Consequences | Contingency Plan
Electrical faults (short circuit, overheating, cable damage) | Low | High | Posing serious safety haz-ards to users and the envi-ronment, and may lead to product failure | We will use a low-voltage power supply and include protective circuitry such as fuses, cur-rent limiting, and thermal protection where ap-propriate. We will improve PCB layout and spacing to reduce short-circuit risk, and ensure wiring insulation, strain relief, and fixation to prevent cable damage.
Keys are too stiff or uncomfortable to press | Medium | Medium | Excessive key force causes fatigue or discomfort, affect-ing the learning experience and product usability. | We will optimise the key feel by conducting pressure and stroke tests; we will adjust the hand feel design based on user test feedback.
Key caps or en-closure cracking (3D printed parts) | Medium | Medium | It may lead to structural failure and may produce sharp edges, posing a risk of scratches to users | To mitigate this, we will avoid thin walls and sharp corners in the 3D print design, and add basic fillets/chamfers in CAD. We will sand any sharp edges
If wireless con-nections are used, latency could cause lights and sounds to be out of sync. | Medium | High | Asynchronous lighting and sound can lead to a chaotic learning pace, reduce inter-activity and teaching effec-tiveness, and affect the over-all learning experience | We will test the prototype in typical demo con-ditions and measure whether sync issues are no-ticeable. If latency is problematic, we will sim-plify the system: reducing wireless features, using local timing on the device, or switching to a wired connection for the demo. We will then define an acceptable tolerance for the as-signment
LED brightness or flicker causing visual discomfort | Low | Medium | Eye strain, discomfort for sensitive users. | We will set a moderate default brightness. We will avoid very low PWM (Pulse-Width Modu-lation) settings and confirm visually that flicker is not obvious in normal use. We will add a caution note for sensitive users and limit demo duration if needed.
Loose or incor-rect modular con-nections between keyboard units | Medium | High | Modules may detach; signal loss; electrical connection issues. | Keyed connectors; magnetic alignment; me-chanical latching; connection detection in firmware.

Table 1. Summary of Risks, Consequences, and Contingency Plans

References

Braun, Melinda, Menschik, Christian, Wahl, Verena, Etges, Theresa, Löwe, Laura-Denise, Wölfel, Matthias, Kiuppis, Florian, Kunze, Christophe, and Renner, Gregor. Current digital consumer technology: barriers, facilitators, and impact on participation for persons with intellectual disabilities – a scoping review. Disability and Rehabilitation, 2025. doi: 10.1080/09638288.2025.2471567.

Emond, Bruno and Schoppek, Wolfgang. Evaluating the impact of visual supports on piano learning through simulated learners. In Smith, Brian K., Borge, Marcela, Sottilare, Robert A., and Schwarz, Jessica (eds.), HCI International 2025 – Late Breaking Papers. Springer Nature Switzerland, 2026.

House of Lords Library. | Access to music educa-
tion in schools. | https://lordslibrary.parliament.uk/
access-to-music-education-in-schools

/, (https://lordslibrary.parliament.uk/access-to-music-education-in-schools/) 2023. Accessed:
2025-01-26.

Liberty Park Music. Guide to piano care & tuning, 2024. URL https://www.libertyparkmusic.com/guide-piano-care-tuning/ (https://www.libertyparkmusic.com/guide-piano-care-tuning/)

Underhill, Jodie. Music: A subject in peril? 10 years on from the first National Plan for Music Education. Technical report, Independent Society of Musicians (ISM), March 2022. URL https://www.ism.org/wp-content/uploads

/2023

/08

/04-ISM_Music-a-subject-of-peril_ A4_March-2022_Online2.pdf (https://www.ism.org/wp-content/uploads/2023/08/04-ISM_Music-a-subject-of-peril_A4_March-2022_Online2.pdf)
Welter, Lucas. | Best digital pianos & keyboards
2026 (all price points). | Piano Dreamers, Jan-
uary 2026. | URL https://www.pianodreamers.com/
best-digital-pianos-and-keyboards

/ (https://www.pianodreamers.com/best-digital-pianos-and-keyboards/)

Wu, Mei-Chun, Hung, Ming-Chien, Chiu, Mai-Lun, Chuang, Cheng-Hung, and Lin, Yu-Bin. Impact of visual cues and feedback on learning performance: Di

fferent
learning styles and cognitive loads. International Research Journal of Engineering Science, Technology and Innovation, 2022. doi: 10.14303

/2315-5663.2022.81.

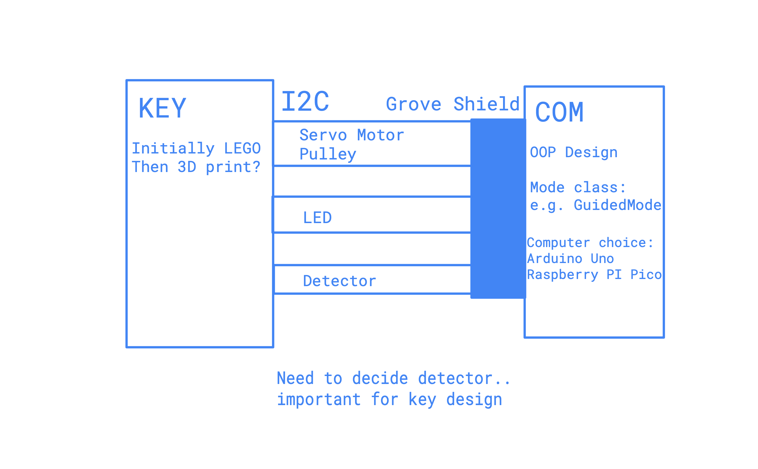
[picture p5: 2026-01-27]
docs/planning/system-design/initial-design.png

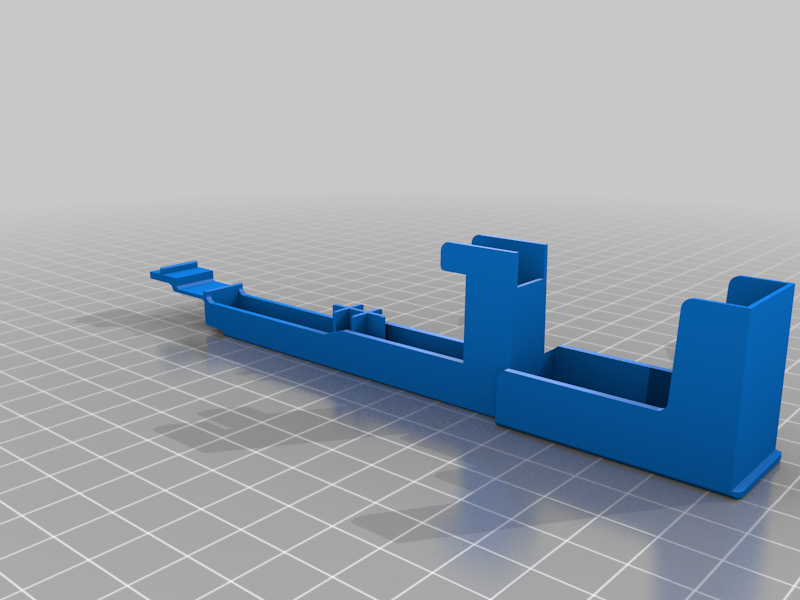
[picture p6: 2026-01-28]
docs/planning/system-design/CAD-keyboard/images/type3-piano-white-key.png

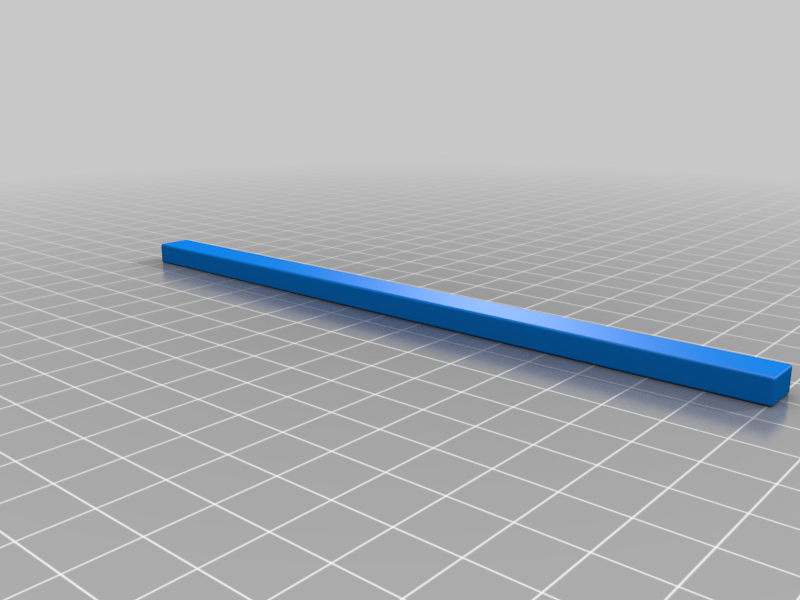
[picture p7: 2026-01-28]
docs/planning/system-design/CAD-keyboard/images/holding-belt.png

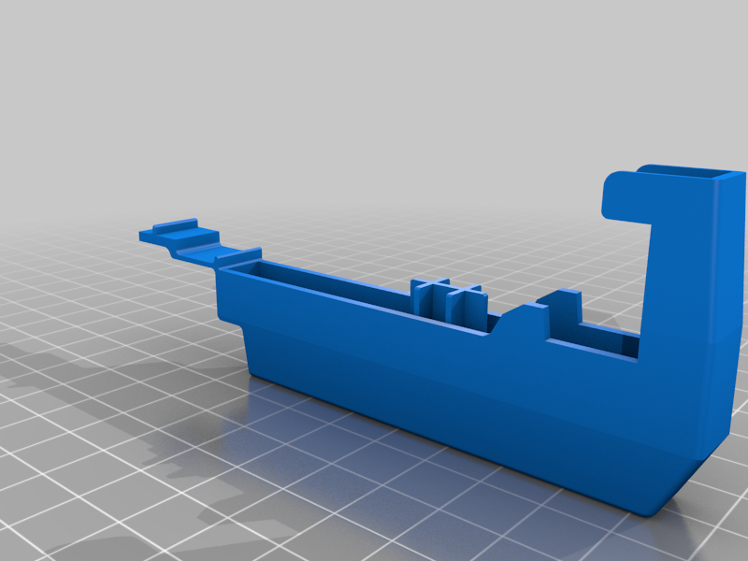
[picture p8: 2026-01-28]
docs/planning/system-design/CAD-keyboard/images/piano_black_key.png

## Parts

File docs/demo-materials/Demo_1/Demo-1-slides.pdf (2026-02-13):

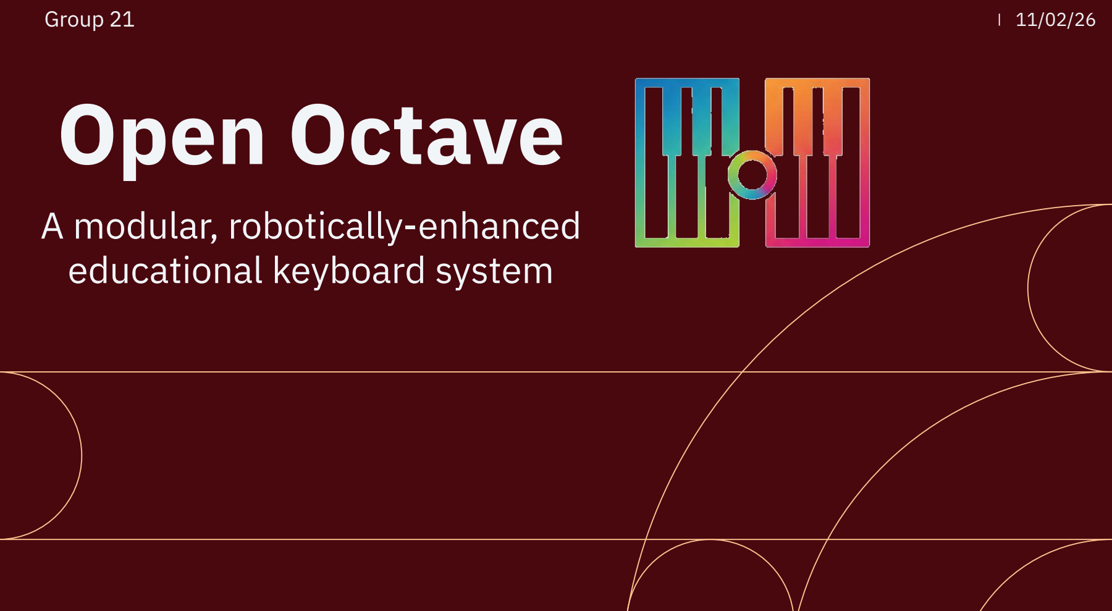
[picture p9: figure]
Open Octave; A modular, robotically-enhanced educational keyboard system; Group 21

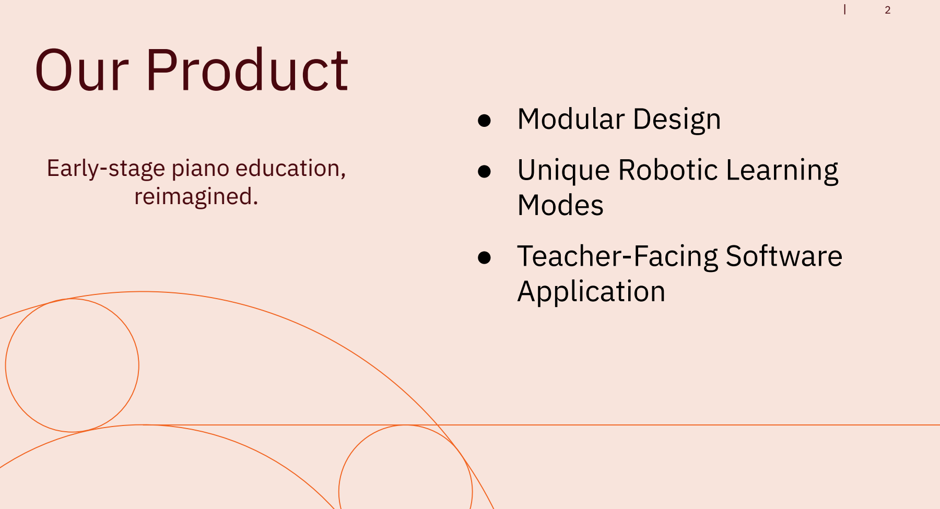
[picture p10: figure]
Our Product; ● Modular Design ● Unique Robotic Learning Modes ● Teacher-Facing Software Application; Early-stage piano education, reimagined.

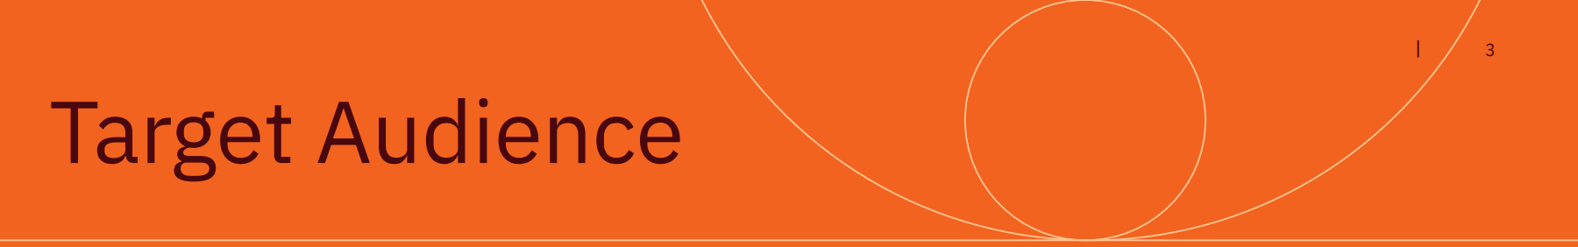
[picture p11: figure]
Target Audience
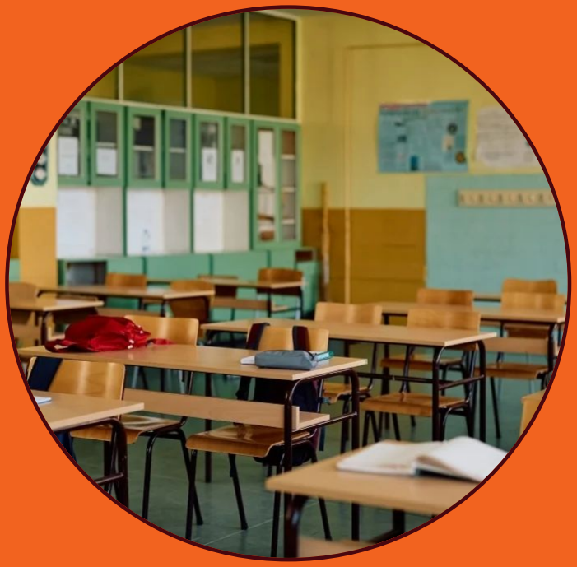
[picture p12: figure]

# BGE Phase Learning

## Likely within the Second to Third CfE levels

# Designed For Complete Beginners

## Most utility for those who have never touched a keyboard

# Music Technology Market

### The UK government's Industrial Strategy:

### double business

### investment in the creative industries, from £17 billion to £31 billion by

2035 (3)

### Music EdTech workshop formats are poised for a

### 16.3% CAGR to

2031. (2)

### The UK creative tech sector attracted the

### third highest amount

### of foreign venture capital investment behind the US and China in 2021 (4)

# The Existing Disparity

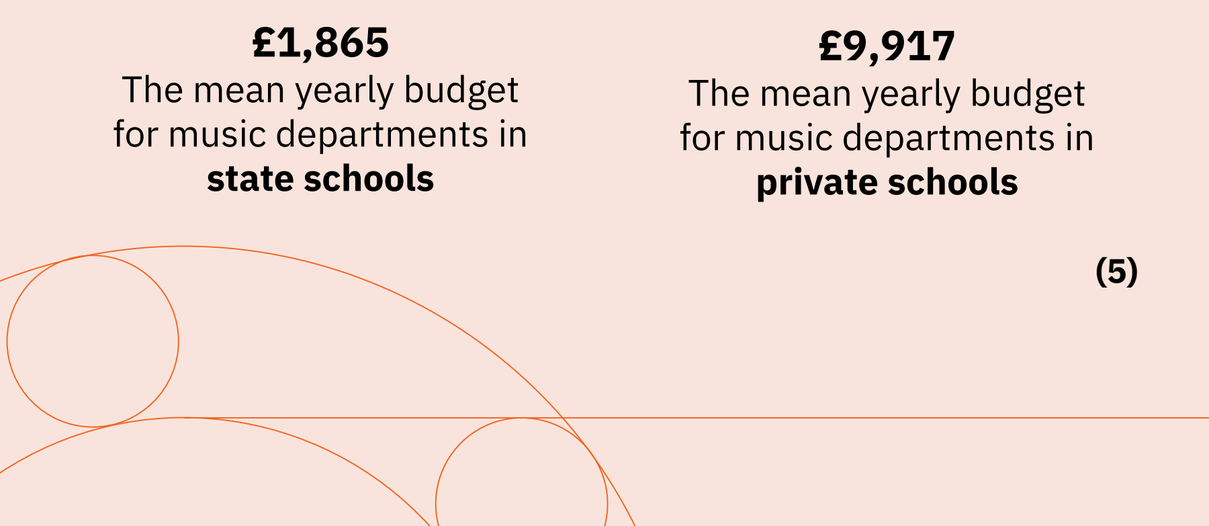
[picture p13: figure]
£1,865 The mean yearly budget for music departments in state schools; £9,917 The mean yearly budget for music departments in private schools

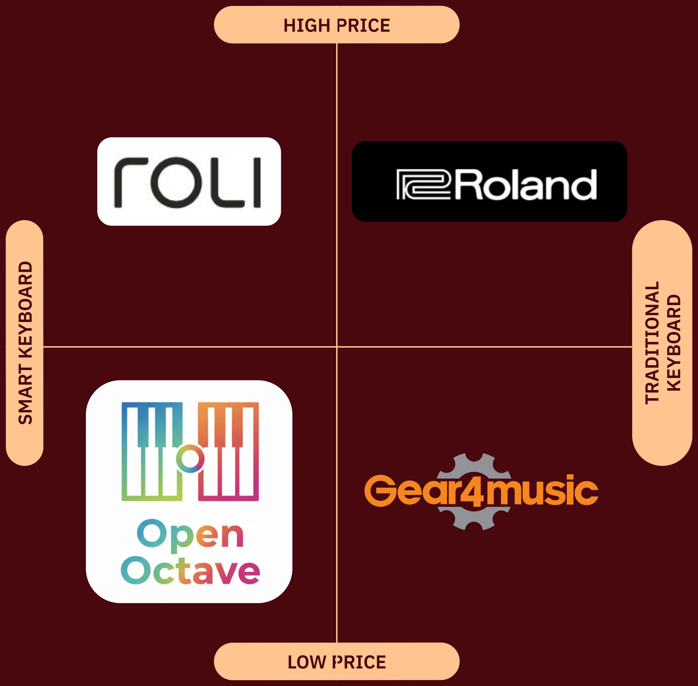
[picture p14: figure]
HIGH PRICE; LOW PRICE; TRADITIONAL KEYBOARD; SMART KEYBOARD

Our Competitors ● Smart learning vs.

## traditional learning

## - Budget-friendly at scale ● Classroom vs. home

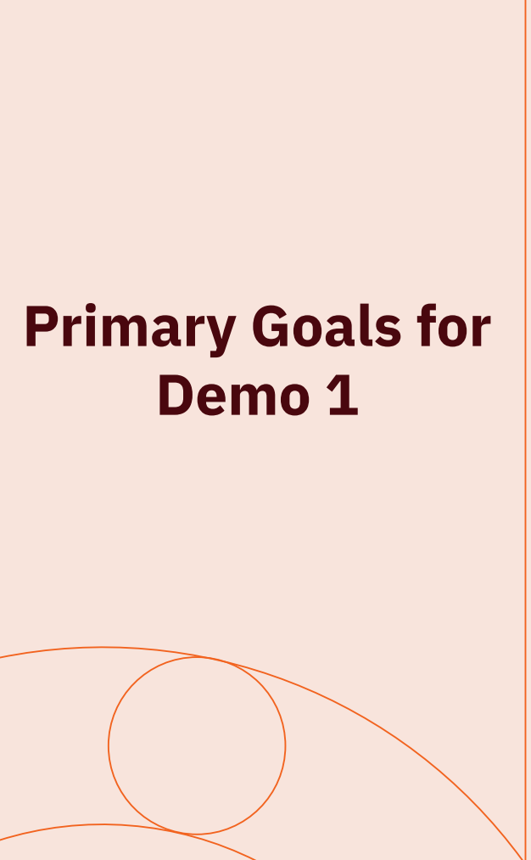
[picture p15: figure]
Primary Goals for Demo 1

### Hardware

- Functional and responsive key mechanism consisting of at least two working keys
- Functional robotic
auto-pressing and lighting up of keys

### Firmware

- Simple program to enable and control the key
mechanisms

# Mechanical Engineering

## Our attempted methods to build keys that fit the Open Octave criteria

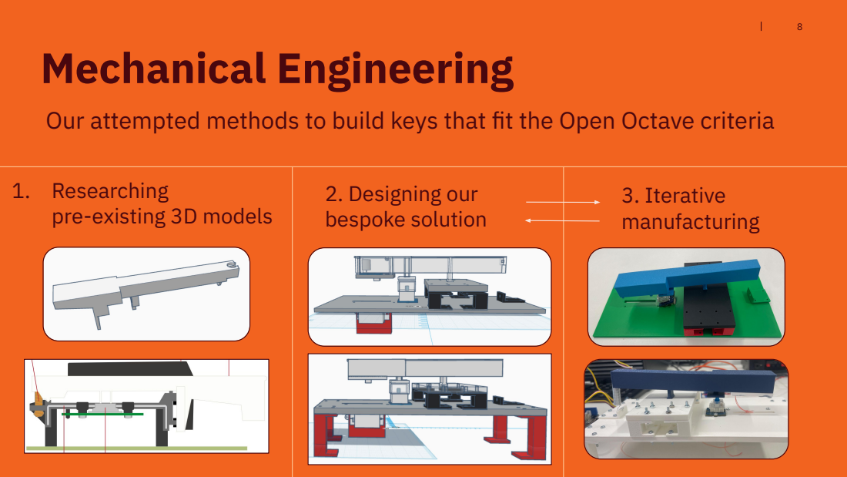
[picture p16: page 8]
2. Designing our bespoke solution; 3. Iterative manufacturing

1. Researching
pre-existing 3D models

# Electrical Engineering


01 | 02 | 03
1. Component Selection | 2. Embedded Programming | 3. Serial Interface

The steps we took to turn our physical mechanisms into a working system

# What’s next for Open Octave?

## Demo 2 and Beyond…

Mechanics:; Electronics:; Software:; ● Printing and integration of full octave including black keys; ● Build frame for keybed to sit in; ● Tailored speaker; solution; Teacher-facing; application, MIDI processing; Extending the current hardware, designing for modularity; Exposing a useful API, designing for networking

# Thank You!

## References:

(1) https://musictechnology.uk/uk-music-tech-sector-faces-critical-lead-or-lose-moment-new-report-reveals/ (https://musictechnology.uk/uk-music-tech-sector-faces-critical-lead-or-lose-moment-new-report-reveals/)
(2) https://www.mordorintelligence.com/industry-reports/onli ne-music-education-market (https://www.mordorintelligence.com/industry-reports/online-music-education-market)
(3) https://assets.publishing.service.gov.uk/media/685943ddb328f1ba50f3cf15/industrial_strategy_creative_industries_sector_plan.pdf (https://assets.publishing.service.gov.uk/media/685943ddb328f1ba50f3cf15/industrial_strategy_creative_industries_sector_plan.pdf)
(4) https://mooreks.co.uk/insights/the-createch-report-2021-venture-capital-firms-back-uk-as-global-createch-hub/ (https://mooreks.co.uk/insights/the-createch-report-2021-venture-capital-firms-back-uk-as-global-createch-hub/)
(5) https://lordslibrary.parliament.uk/access-to-music-education-in-schools/



“For interaction in a networked music performance to feel natural, the latency generally must be kept below 30 milliseconds, the bound of human perception…” –Wikipedia

https://en.wikipedia.org/wiki/Networked_music_performance


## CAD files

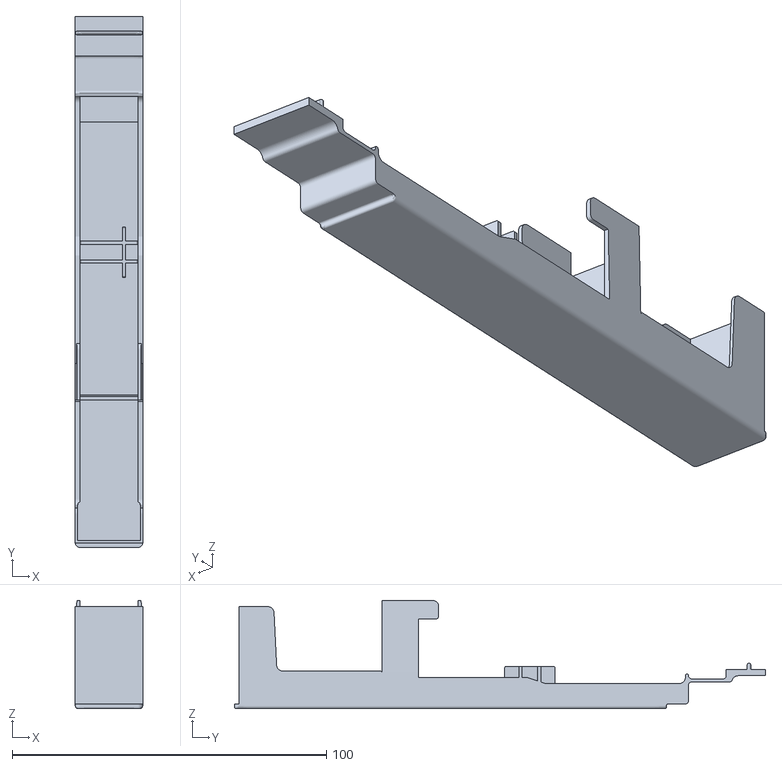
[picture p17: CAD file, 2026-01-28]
docs/planning/system-design/CAD-keyboard/files/full-piano-white-key.stl
21.5 x 169.0 x 34.5

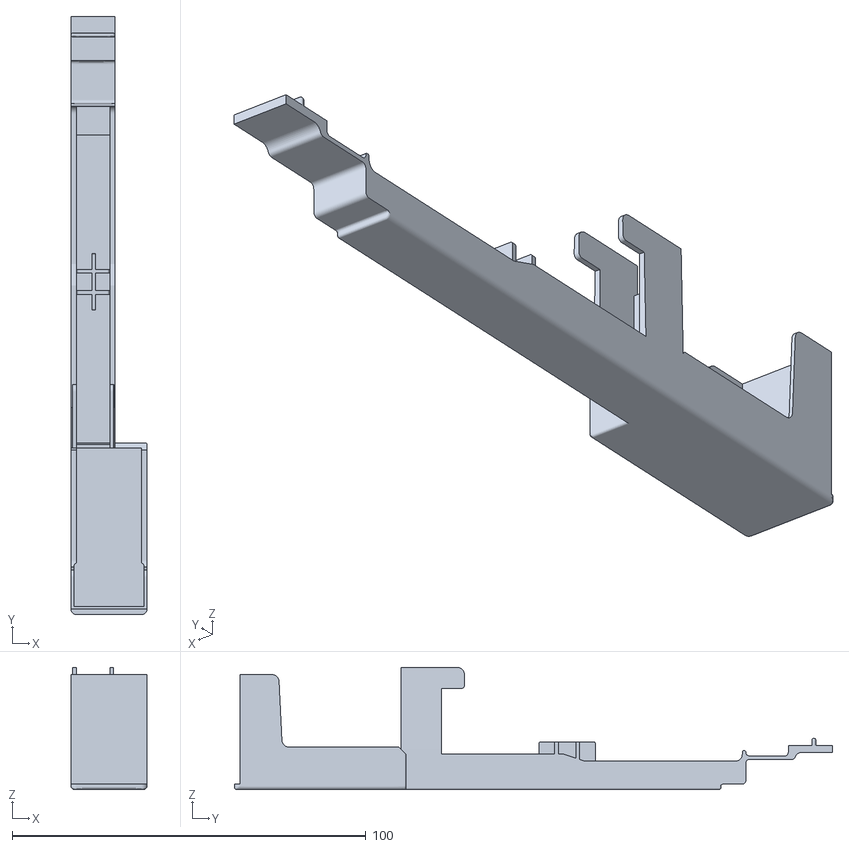
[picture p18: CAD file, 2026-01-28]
docs/planning/system-design/CAD-keyboard/files/type2-piano-white-key.stl
21.5 x 169.0 x 34.5

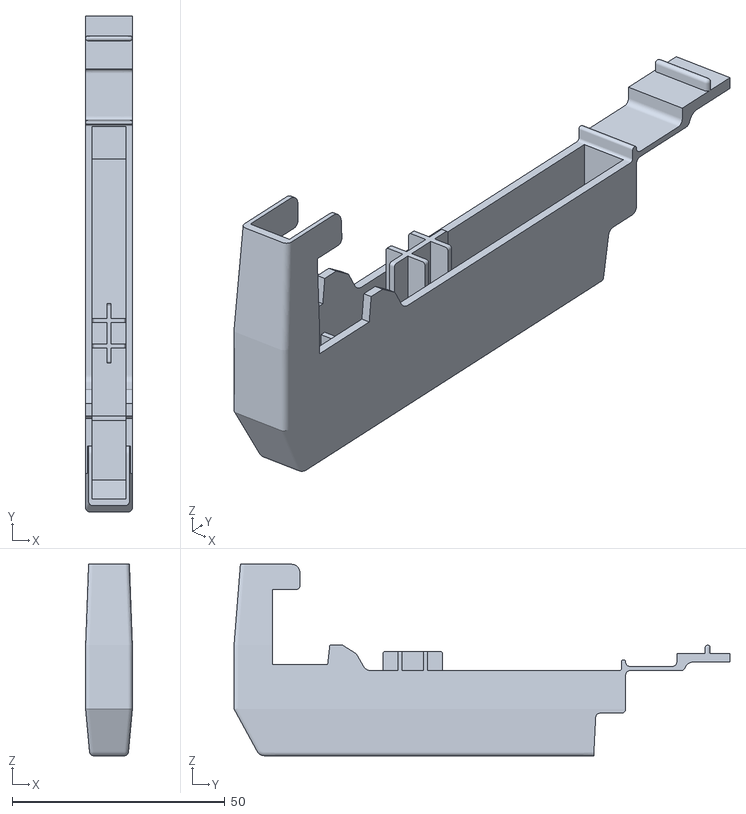
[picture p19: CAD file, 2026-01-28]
docs/planning/system-design/CAD-keyboard/files/piano_black_key.stl
11.0 x 116.5 x 45.0

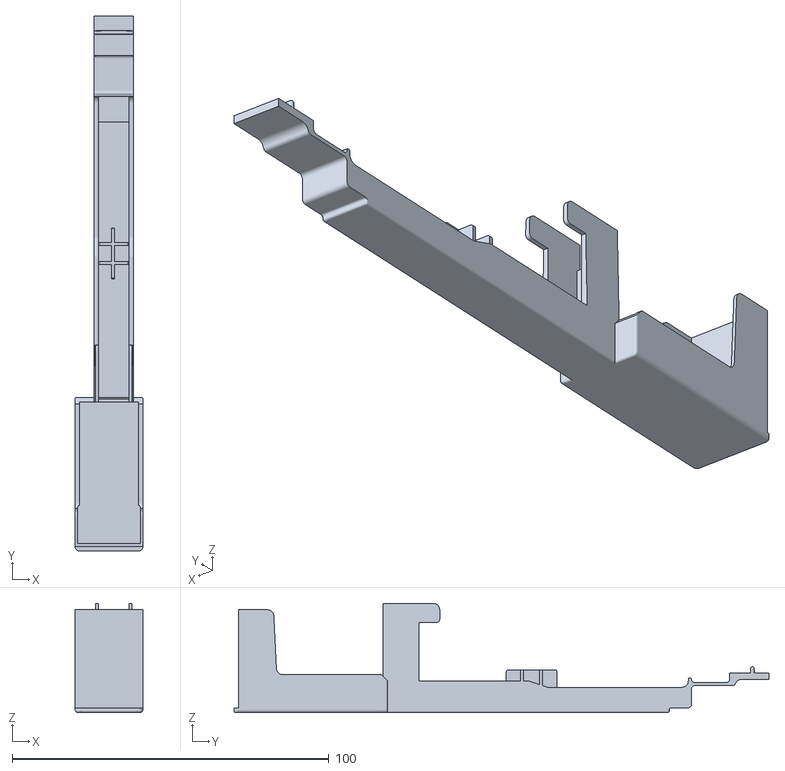
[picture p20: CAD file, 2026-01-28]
docs/planning/system-design/CAD-keyboard/files/type4-piano-white-key.stl
21.5 x 169.0 x 34.5

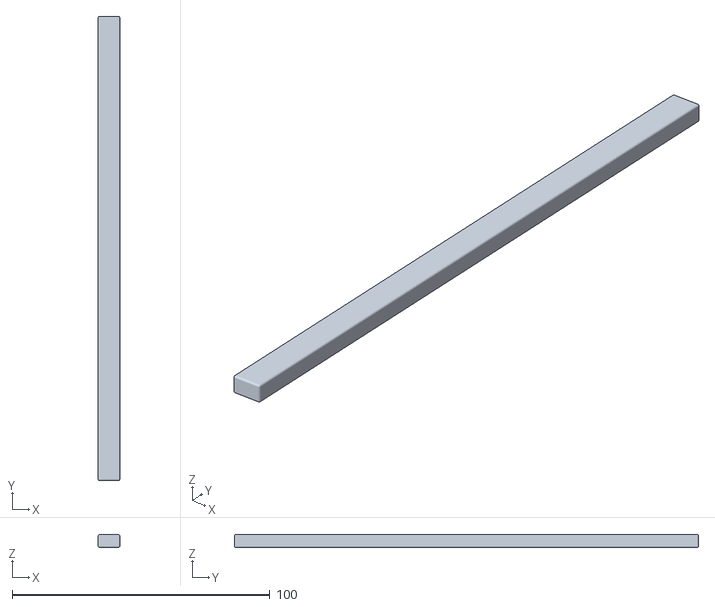
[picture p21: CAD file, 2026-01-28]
docs/planning/system-design/CAD-keyboard/files/holding-belt-long.stl
8.40 x 180.0 x 5.00

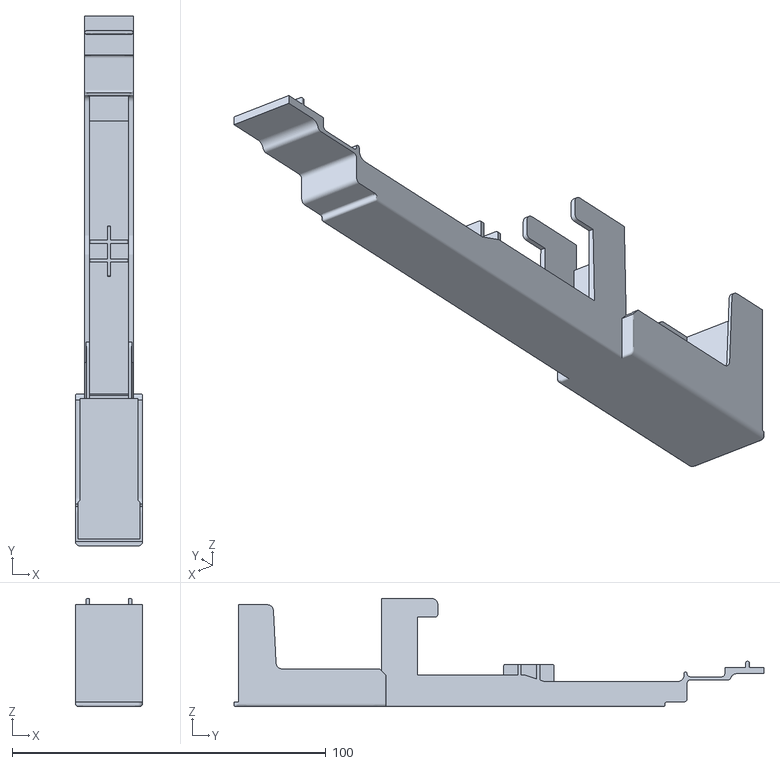
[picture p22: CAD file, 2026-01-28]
docs/planning/system-design/CAD-keyboard/files/type5-piano-white-key.stl
21.5 x 169.0 x 34.5

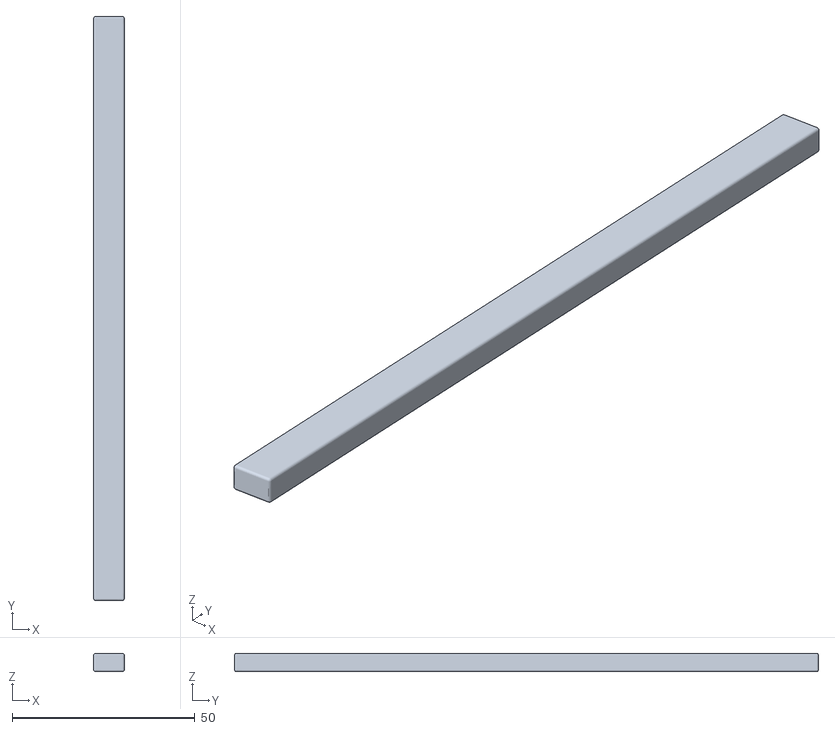
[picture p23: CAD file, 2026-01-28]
docs/planning/system-design/CAD-keyboard/files/holding-belt.stl
8.40 x 160.0 x 5.00

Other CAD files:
docs/planning/system-design/CAD-keyboard/files/type3-piano-white-key.stl
docs/planning/system-design/CAD-keyboard/files/type1-piano-white-key.stl

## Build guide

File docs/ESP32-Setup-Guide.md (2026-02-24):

# ESP32 Setup Guide — Firmware V4

This guide covers how to set up the ESP32 and upload Firmware V4.

### 1. Install Arduino IDE

1. Download Arduino IDE
2. Install with default settings and open it to confirm it works.
3. Go to preferences and make "Sketchbook location" point to the Arduino folder in this repo.

### 2. Add ESP32 Board Support

1. Open **File → Preferences** (macOS: **Arduino IDE → Settings**).
2. In the **"Additional boards manager URLs"** field, paste: 
   `https://raw.githubusercontent.com/espressif/arduino-esp32/gh-pages/package_esp32_index.json`
3. Click OK.
4. Go to **Tools → Board → Boards Manager**, search for `esp32`, and install **"esp32 by Espressif Systems"**. This may take a few minutes.

### 3. Select Board and Port

1. Plug the ESP32 into your computer via USB.
2. Go to **Tools → Board → esp32** and select **"DFRobot FireBeetle-ESP32"** (or **"ESP32 Dev Module"** if that's not listed).
3. Go to **Tools → Port** and select the port that appeared when you plugged in the board.
   - macOS: looks like `/dev/cu.usbserial-XXXXX`
   - Windows: looks like `COM3`, `COM4`, etc.
   - Linux: looks like `/dev/ttyUSB0`
4. If no port appears, you probably need a USB driver — see the [Troubleshooting](#troubleshooting) section.

### 4. Upload the Firmware

1. In Arduino IDE, open `firmware_v4.ino`.
2. Click **→ (Upload)** to flash the firmware to the ESP32.
3. Wait for "Done uploading." in the console.

### 5. Check the Serial Monitor

1. Open **Tools → Serial Monitor**.
2. Set the baud rate to **115200** (bottom-right dropdown).
3. Press the **RST** button on the ESP32 (or re-plug USB).
4. You should see the startup log, including:
   ```
   OPEN OCTAVE FIRMWARE V4 - INIT
   [SETUP] Validating hardware config... OK
   [SETUP] Validating sequence data... OK
   ...
   [WIFI] Access Point started: Open Octave
   [WIFI] IP Address: 192.168.4.1
   ...
   [SETUP] Complete! Starting in MANUAL mode
   ```
5. You can send commands to the ESP32 through the serial monitor through the text box at the top.

### 6. Connect Over WiFi for wireless commands

The ESP32 creates its own WiFi network (it doesn't join yours).

- **SSID:** `Open Octave`
- **Password:** `oop321321`

After connecting, you won't have internet — that's normal.

The ESP32 runs a WebSocket server at `ws://192.168.4.1:81`. You can send commands (the same commands as the serial monitor) using any WebSocket client:

- **Browser:** go to https://websocketking.com, connect to `ws://192.168.4.1:81`, and type commands.
- **Command line:**
  ```bash
  npm install -g wscat
  wscat -c ws://192.168.4.1:81
  ```

## Optional - Using the Proxy server

### 7. Send Commands Through the Controller Server

The `controller/` folder contains a Node.js proxy server that sits between a web app and the ESP32. It translates REST API calls into the single-character commands the firmware expects, and support both wired and wireless routing of commands.

#### Setup

1. Make sure you have Node.js 18+ installed.
2. Navigate to the controller folder and install dependencies:
   ```bash
   cd controller
   npm install
   ```
3. Create a `.env` file in `controller/` with these settings:
   ```
   APP_PORT=3000
   COMM_MODE='WIFI'
   ESP32_IP=192.168.4.1
   WS_PORT=81
   SERIAL_PORT='/dev/cu.usbserial-XXXXX'
   ```
   - Use `COMM_MODE='WIFI'` to communicate over WiFi, or `COMM_MODE='SERIAL'` for USB.
   - If using serial, update `SERIAL_PORT` to your actual port (check **Tools → Port** in Arduino IDE).
4. Start the server:
   ```bash
   npm start
   ```
   You should see:
   ```
   OPEN OCTAVE CONTROLLER
   Server running at: http://localhost:3000
   Mode: WIFI
   ```

#### Sending Commands

You can send commands to the ESP32 through the server using `curl` or any HTTP client:

```bash
# Switch mode
curl -X POST "http://localhost:3000/api/modes?mode=manual"
curl -X POST "http://localhost:3000/api/modes?mode=guided"
curl -X POST "http://localhost:3000/api/modes?mode=teaching"

# Sequence control
curl -X POST "http://localhost:3000/api/seq/control?cmd=start"
curl -X POST "http://localhost:3000/api/seq/control?cmd=stop"
curl -X POST "http://localhost:3000/api/seq/control?cmd=next"
curl -X POST "http://localhost:3000/api/seq/control?cmd=prev"

# Select a sequence by number (0-7)
curl -X POST "http://localhost:3000/api/seq/select?id=5"

# List all sequences
curl http://localhost:3000/api/seq/list

# Run hardware tests
curl -X POST "http://localhost:3000/api/test?target=leds"
curl -X POST "http://localhost:3000/api/test?target=servos"

# Check status
curl http://localhost:3000/api/status
```

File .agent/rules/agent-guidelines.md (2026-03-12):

---
trigger: always_on
---

# Open Octave Agent Guidelines

> Ensure consistent, safe, and effective development for the Open Octave robotically enhanced educational keyboard system.

## Project Context & Knowledge Base

`.agent/rules/Open-Octave.md` — Core project details and milestones. Use as a core source of truth for the Open Octave project.

## Firmware Development Standards

### File Structure
Example firmware file structure (firmware V4 used as example):
```
Arduino/
|── OO-firmware/firmware_v4/
|    └── firmware_v4.ino        # Main logic
└── libraries/
    ├── firmware_v4_config/firmware_v4_config.h           # Hardware config, constants
    |── firmware_v4_sequences/firmware_v4_sequences.h     # Sequence definitions
    └── firmware_v4_debug/firmware_v4_debug.h             # Debug macros
```

### Clang Errors
The firmware code is written for the Arduino IDE. This can cause "false errors" within the Antigravity IDE due to missing Arduino-specific dependencies, the user is aware of this and you do not need to inform them when finding these false errors.

### Code Modification Protocols
Rule 1: **CRITICAL** Follow `git-standards.md`:
- **MUST**: Properly utilize git for version control based on the instructions in `git-standards.md`

Rule 2: Surgical Edits Only:
- **MUST**: Only modify code directly related to request
- **MUST NOT**: Refactor, reformat, or rename unrelated code

Rule 3: Respect Existing Patterns
- Follow existing structure, naming, and documentation style
- Use same conventions (e.g., `#define` vs `const int`)

### Educational Explanations
When integrating new concepts, techniques, tools, or libraries into the code, you should always provide an accompanying beginner-friendly explanation to help the user understand it and how you used it.

### Memory & Performance Optimization
Arduino Uno Constraints:
- **Flash**: 32 KB (constants, code)
- **SRAM**: 2 KB **CRITICAL** — Minimize usage!

Always Do:
- Use `F()` or `PROGMEM` for string literals
- Use smallest data types possible (`uint8_t` vs `int`)
- Pass structs by reference (`const SequenceStep &step`)

Never Do:
- Dynamic allocation (`new`, `malloc`) — causes fragmentation
- Arduino `String` class — use `char[]`
- Block `loop()` with `delay()` — use `millis()` timing

## Core Principles

1. **Minimize Changes** — Only modify what's necessary
2. **Utilize Git** - Follow the instructions in `git-standards.md`
3. **Educate Team** — Explain new embedded/C++ concepts
4. **Optimize Memory** — Flash for constants, minimize SRAM
5. **Protect Hardware** — Validate angles, pins, etc.
6. **Non-Blocking Code** — Use `millis()`, avoid `delay()` in loop
7. **Consistent Style** — Match existing patterns
8. **Document Clearly** — Update comments and docs

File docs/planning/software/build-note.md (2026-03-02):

# Open Octave Software (Demo 2) – Build Notes

This document explains how to set up and run the Open Octave software on a new laptop for Demo 2.

Demo 2 software goals:
- Provide a simple web UI to control the robot via the controller.
- Controller communicates to firmware primarily over USB Serial.
- Optional: WiFi WebSocket transport for testing if available.
- Maintain a software-side sequence library in SQLite.
- Upload exactly one selected sequence to firmware (firmware holds default + last uploaded).

---

## Repo structure (relevant parts)

- `controller/`
  - `server.js` (Node controller)
  - `database/sqlite.js` (SQLite DB layer for sequences)
  - `database/open-octave.sqlite3` (created at runtime if missing)
- `software/web/`
  - Vite + React UI

---

## Prerequisites (new laptop)

1. Install Node.js (minimum: Node 20.x LTS)
2. Install npm (usually comes with Node)
3. For Serial control:
   - Install the appropriate USB serial driver if required by your board (varies by board/USB chip).
   - Have a USB cable that supports data (not charge-only).

Optional tools (useful for debugging):
- `curl` (macOS usually has it)
- `sqlite3` CLI (macOS usually has it; if not, install via Homebrew)
- DB Browser for SQLite (GUI) if you prefer

---

## Install steps (first time)

From repo root:

### 1) Install controller dependencies
```bash
cd controller
npm install
```

### 2) Install web UI dependencies
```bash
cd ../software/web
npm install
```

---

## Environment settings (controller)

Controller reads env vars via `controller/.env` (dotenv).

Create `controller/.env` if missing.

Minimal recommended for Demo 2 (Serial primary):

- `APP_PORT=3000`
- `COMM_MODE=SERIAL`
- `SERIAL_PORT=/dev/cu.usbserial-XXXX` (macOS example)
- `SQLITE_PATH=` (optional, defaults to `controller/database/open-octave.sqlite3`)

Notes:
- `SERIAL_PORT` is machine-specific. Each teammate must set it to their own serial device path.
- On macOS, serial devices usually look like:
  - `/dev/cu.usbserial-XXXX`
  - `/dev/cu.usbmodemXXXX`

To find your port on macOS:
```bash
ls /dev/cu.*
```

---

## Running the system

### Terminal 1: start controller
```bash
cd controller
node server.js
```

Check it is running:
```bash
curl http://localhost:3000/api/health
```

### Terminal 2: start web UI
```bash
cd software/web
npm run dev
```

Open the Vite URL in the browser (usually `http://localhost:5173`).

---

## Using the UI (Demo 2 workflow)

### 1) Connect (Serial)
Open the UI → **Connect** tab:
- Transport: `SERIAL`
- Serial port: enter your local port path (example `/dev/cu.usbmodem1101`)
- Click **Connect**

Verify:
- **Settings** tab shows: Connected = true, Transport = SERIAL
- **Logs** tab shows incoming lines once the device prints anything

### 2) Basic control tests (safe tests)
Use **Control** tab:
- Mode buttons (manual / guided / teaching) -> sends `m`, `a`, `f`
- Start/Stop -> `s` / `x`
- Next/Prev -> `n` / `p`

Use **Settings → Quick Diagnostics**:
- `Refresh Health`
- `Refresh State`
- `Refresh Logs`
- `Status (GET /api/status)` (sends `?`)
- `Current seq (GET /api/seq/list, l)` (sends `l`)

Important note:
- `GET /api/seq/list` returns a “command sent” confirmation.
- The actual printed sequence content appears in **Logs**.

### 3) Sequences (software library + upload)
Open **Sequences** tab.

There are two sections:
1) **Software library (SQLite)**
2) **Current sequence on device (firmware 'l')** (verification via logs)

To seed presets:
- Click **Seed demos**
  - Seeds 8 preset sequences that match the firmware’s preset patterns (colors ignored; key+duration preserved).

To create/edit a sequence:
- Go **Settings → Create / Update sequence (SQLite)**
- Paste JSON and click **Save to DB**
- Then return to **Sequences** tab and select it from the dropdown.

To upload a DB sequence to firmware:
- **Sequences tab → Software library**
- Select a sequence
- Click **Upload to device**
- You should see an upload summary (sentCount, ok, etc.)
- Verify by clicking **Refresh (l)** and checking Logs output.

Firmware behavior reminder:
- Firmware stores only the default sequence + the last uploaded sequence.
- Upload overwrites any previously uploaded sequence.

---

# WiFi (WebSocket) Connection Setup – Demo 2

WiFi mode is optional for Demo 2 but fully supported. Serial remains the primary demo path. Use WiFi only if required or for testing flexibility.

---

## 1) Firmware Requirements

The firmware must:
- Start a WebSocket server (commonly on port `81`)
- Print its IP address over Serial at boot (recommended)
- Accept single-character commands over WebSocket

Default assumptions (adjust if your firmware differs):

- ESP32 IP (AP mode): `192.168.4.1`
- WebSocket Port: `81`

---

## 2) Connect Laptop to ESP32

### If ESP32 is in Access Point (AP) mode:
1. Open laptop WiFi settings.
2. Connect to the ESP32 network (example: `OpenOctave_AP`).
3. Default gateway/IP is usually `192.168.4.1`.

### If ESP32 is in Station (STA) mode:
1. Ensure laptop and ESP32 are on the same local network.
2. Find ESP32 IP:
   - Check Serial boot logs.
   - Or check router device list.

---

## 3) Controller Environment (.env)

If starting directly in WiFi mode:

```
APP_PORT=3000
COMM_MODE=WIFI
ESP32_IP=192.168.4.1
WS_PORT=81
```

Then start controller:

```bash
cd controller
node server.js
```

You should see:
```
[INIT] Starting in WIFI (WebSocket) mode targeting ...
[WS] Connecting to ws://...
```

---

## 4) Connect via UI (Recommended Method)

Instead of restarting controller, you can switch transport from the UI:

1. Go to **Connect tab**
2. Select `WIFI`
3. Enter:
   - ESP32 IP (example `192.168.4.1`)
   - WS Port (example `81`)
4. Click **Connect**

Verify:
- Settings tab shows `Transport: WIFI`
- `Connected: true`
- Logs tab shows `[ESP32] ...` lines

---

## 5) Test WiFi Connection

### Quick test from UI:
- Press `Manual` (sends `m`)
- Press `Status` (sends `?`)
- Click `Current seq (l)`

Check Logs tab for responses.

### Quick test from terminal:
```bash
curl -X POST "http://localhost:3000/api/modes?mode=manual"
```

If WebSocket is connected, response should be:
```json
{ "success": true, "mode": "websocket", "cmd": "m" }
```

---

## 6) Important WebSocket Framing Rule (Handled Automatically)

Firmware behavior:
- Single-character commands must be sent WITHOUT newline.
- Multi-line upload strings can be newline-terminated.

The controller automatically handles this:
- WebSocket single-char → no newline
- Upload lines → newline added
- Serial → always newline

No manual adjustment needed.

---

## 7) Common WiFi Debugging Steps

### WebSocket Not Connected
- Ensure laptop is on the correct WiFi network.
- Confirm IP address is correct.
- Ping the ESP32:
```bash
ping 192.168.4.1
```
- Restart controller.

### Connected but No Logs
- Check firmware is printing over WebSocket.
- Verify WebSocket port matches firmware.

### Reconnect Behavior
The controller auto-reconnects with exponential backoff:
1s → 2s → 4s → 8s → 10s (max)

If switching back to Serial, use UI Disconnect first.

---

WiFi mode is stable for Demo 2 but Serial remains the recommended primary transport for live demonstration reliability.

## Database management (SQLite)

### Where the DB is stored
Default path:
- `controller/database/open-octave.sqlite3`

If `SQLITE_PATH` is set in `.env`, the DB file will be at that path instead.

### Reset DB (clean slate)
Stop the controller first, then delete the DB file:
```bash
rm controller/database/open-octave.sqlite3
```

Restart controller, then re-seed presets from UI.

This is the recommended approach for Demo 2 if the dropdown shows old sequences.

### Delete a single sequence (CLI)
Use sqlite3:

```bash
sqlite3 controller/database/open-octave.sqlite3
```

Inside sqlite prompt:
```sql
SELECT id, name, updated_at FROM sequences ORDER BY updated_at DESC;
DELETE FROM sequences WHERE id = 'twinkle';
.quit
```

### Edit a sequence (CLI)
```bash
sqlite3 controller/database/open-octave.sqlite3
```

Example: update name:
```sql
UPDATE sequences SET name='New Name', updated_at=strftime('%Y-%m-%dT%H:%M:%fZ','now') WHERE id='twinkle';
.quit
```

Note:
- The software stores sequence steps as JSON in `data_json`.
- Easiest edit path is usually via the UI (Settings → Create/Update) rather than editing JSON by hand in SQL.

---

## Debugging guide (how to diagnose issues quickly)

### A) “UI shows connected but nothing happens”
1. Check **Settings → Refresh Health** and **Refresh State**
2. Check **Logs** for any outgoing “CTRL send” lines and any incoming “ESP32” lines
3. Verify serial port path is correct:
   - macOS: `ls /dev/cu.*`
4. If Serial is stuck, disconnect/reconnect from UI.
5. If needed, restart controller.

### B) “Upload works but sequence output doesn’t show”
1. Upload summary should show `ok: true` and `sentCount`
2. Click **Current seq (l)** and look at **Logs**
3. If logs don’t show printed sequence, firmware may not be printing it, or the transport isn’t receiving logs.

### C) “Prefixed only shows nothing”
Prefixed filter only shows lines that start with:
- `ACK `
- `STATUS `
- `EVT `
- `ERR `

Many firmware prints are plain logs; use Prefixed-only only when you expect protocol-prefixed lines.

### D) “Can’t connect to Serial”
- Make sure nothing else is using the serial port (Arduino IDE Serial Monitor, another script, etc.)
- Replug USB
- Check the port path changed

### E) “Web UI doesn’t show latest changes”
- Restart Vite:
```bash
cd software/web
npm run dev
```
- Hard refresh browser: Cmd + Shift + R

---

## Features included in Demo 2 software

Controller (`controller/server.js`):
- Serial + WiFi (WebSocket) transports, switchable via UI
- Command translation to single-char firmware commands
- Demo 2 framing workaround:
  - WebSocket: single-char commands send without newline, multi-line upload includes newline
  - Serial: always newline-terminated
- In-memory log buffer and `/api/logs`
- Controller state mirror `/api/state`
- SQLite sequence library endpoints:
  - list/get/create/update sequences
  - seed preset sequences (8 presets)
  - upload one sequence to firmware using generated U/S/E lines

Web UI (`software/web`):
- Connect tab: select transport and connect/disconnect
- Control tab: modes + sequence control commands
- Sequences tab:
  - software library (SQLite): seed/select/upload
  - device verification via firmware `l` + logs
- Logs tab: tail, auto, prefixed-only filter, search, copy, clear UI
- Settings tab:
  - connection mirror + reset mirror
  - quick diagnostics buttons
  - create/update sequence via JSON textarea

---

## Known intentional Demo 2 deviations (documented decisions)

- Firmware newline framing differs per transport:
  - Serial requires newline to execute commands.
  - WebSocket single-char commands are sent without newline due to firmware dispatch rules.
- SQLite schema is simplified for Demo 2:
  - steps stored as JSON (not normalized relational tables).
- Raw command sender is intentionally not enabled in UI to reduce risk to hardware during Demo 2.

---

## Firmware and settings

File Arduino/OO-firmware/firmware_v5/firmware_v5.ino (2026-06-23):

/*
 * FIRMWARE V5
 *
 * Each module is a 12-key octave with servo actuators, per-key LEDs, and a
 * speaker. Modules daisy-chain together via serial to form larger keyboards,
 * with automatic master/slave role assignment through a heartbeat protocol.
 *
 * Sequence playback operates in one of two modes:
 *   - GUIDED:  LEDs light up sequentially; the user must press and hold the
 *              correct key for the step's duration before the sequence advances.
 *   - TEACHING: LEDs light up and servos auto-press keys to demonstrate melodies.
 *
 * Sound is always triggered by button presses — whether the user presses a key
 * or a servo pulls it down, the button underneath is what triggers the sound.
 *
 * NETWORKING:
 *   The master module connects as a WiFi client to the controller's network and
 *   opens a WebSocket connection to the controller server. Commands and log
 *   output flow over this link as a "serial-over-WiFi" transport. Slave modules
 *   do not use WiFi; they receive commands from the master via the daisy-chain.
 */

#include "Arduino.h"
#include "HardwareSerial.h"
#include "PCA9685.h"
#include "clsPCA9555.h"
#include "firmware_V5_config.h"
#include "firmware_V5_debug.h"
#include <Adafruit_NeoPixel.h>
#include <Wire.h>
#include <WiFi.h>
#include <WebSocketsClient.h>
#include <cstdint>
#include <driver/i2s.h>
#include <math.h>

// ============ HARDWARE DEFINITIONS ============

Key keys[NUM_KEYS] = {
    {KEY0_BUTTON_PIN, KEY0_LED_INDEX, KEY0_SERVO_CHANNEL, KEY0_NOTE, false}, // C4
    {KEY1_BUTTON_PIN, KEY1_LED_INDEX, KEY1_SERVO_CHANNEL, KEY1_NOTE, false}, // C#4
    {KEY2_BUTTON_PIN, KEY2_LED_INDEX, KEY2_SERVO_CHANNEL, KEY2_NOTE, false}, // D4
    {KEY3_BUTTON_PIN, KEY3_LED_INDEX, KEY3_SERVO_CHANNEL, KEY3_NOTE, false}, // D#4
    {KEY4_BUTTON_PIN, KEY4_LED_INDEX, KEY4_SERVO_CHANNEL, KEY4_NOTE, false}, // E4
    {KEY5_BUTTON_PIN, KEY5_LED_INDEX, KEY5_SERVO_CHANNEL, KEY5_NOTE, false}, // F4
    {KEY6_BUTTON_PIN, KEY6_LED_INDEX, KEY6_SERVO_CHANNEL, KEY6_NOTE, false}, // F#4
    {KEY7_BUTTON_PIN, KEY7_LED_INDEX, KEY7_SERVO_CHANNEL, KEY7_NOTE, false}, // G4
    {KEY8_BUTTON_PIN, KEY8_LED_INDEX, KEY8_SERVO_CHANNEL, KEY8_NOTE, false}, // G#4
    {KEY9_BUTTON_PIN, KEY9_LED_INDEX, KEY9_SERVO_CHANNEL, KEY9_NOTE, false}, // A4
    {KEY10_BUTTON_PIN, KEY10_LED_INDEX, KEY10_SERVO_CHANNEL, KEY10_NOTE, false}, // A#4
    {KEY11_BUTTON_PIN, KEY11_LED_INDEX, KEY11_SERVO_CHANNEL, KEY11_NOTE, false}  // B4
};

ServoDriver servoDriver;
PCA9555 ioport(0x20);

Adafruit_NeoPixel leds(NUM_KEYS, LED_STRIP_PIN, NEO_GRB + NEO_KHZ800);

WebSocketsClient webSocket;

HardwareSerial UpstreamSerial(1);
HardwareSerial DownstreamSerial(2);

// ============ GLOBAL STATE ============

bool on = true;
unsigned long lastOnOffSwitchTime = 0;

bool isMaster = true;
uint8_t moduleChainIndex = 0;
uint8_t numModulesInChain = 1;

uint8_t currentOctave = DEFAULT_OCTAVE;
uint8_t chainBaseOctave = DEFAULT_OCTAVE;

unsigned long timeLastHeartbeatSent = 0;
unsigned long timeLastHeartbeatReceived = 0;
unsigned long timeLastHeartbeatReplyReceived = 0;

bool uploadingSequence = false;
uint8_t uploadStepCount = 0;
Sequence uploadSequenceBuffer;

SequenceMode currentSequenceMode;
Sequence currentSequence;
bool sequenceRunning = false;
int currentSequenceStepIndex = 0;
unsigned long currentStepStartTime = 0;
unsigned long lastSequenceButtonPressTime = 0;

SynthMode currentSynthMode = SYNTH_KARPLUS_STRONG;
unsigned long promotionSuppressionTime = 0;  // suppress buttons briefly after promotion
#define CURRENT_STEP currentSequence.steps[currentSequenceStepIndex]
#define PREVIOUS_STEP currentSequence.steps[currentSequenceStepIndex - 1]

// To keep track of key presses across other chained modules for the 
// master to handle sequences
bool globalKeyIsPressed[MAX_TOTAL_KEYS] = {false};
unsigned long globalKeyPressTime[MAX_TOTAL_KEYS] = {0};
unsigned long toneStartTime[MAX_TOTAL_KEYS] = {0};

bool waitingForServoRelease = false;
unsigned long servoReleaseStartTime = 0;

bool recording = false;
uint8_t recStepCount = 0;
uint8_t recChordKeys[MAX_KEYS_PER_STEP];
uint8_t recChordNumKeys = 0;
unsigned long recChordStartTime = 0;

bool testLogEnabled = false;
uint16_t testLogRunId = 0;
uint16_t testLogEventId = 0;
int8_t testLogLastManualKey = -1;
unsigned long testLogLastManualTime = 0;
uint8_t testLogManualRepeatStreak = 0;
unsigned long testLogExpectedNextStepStartTime = 0;
int8_t testLogLastAutoKey = -1;
uint8_t testLogAutoRepeatStreak = 0;

unsigned long lastWifiCheckTime = 0;
bool isWifiConnected = false;
bool isConnectingWifi = false;
bool wsReady = false;  // Prevents wsSendLog() from running before webSocket.begin()

char serialBuf[SERIAL_BUF_SIZE];
uint8_t serialBufPos = 0;
bool serialBufOverflow = false;

char upstreamSerialBuf[SERIAL_BUF_SIZE];
uint8_t upstreamSerialBufPos = 0;
bool upstreamSerialBufOverflow = false;

char downstreamSerialBuf[SERIAL_BUF_SIZE];
uint8_t downstreamSerialBufPos = 0;
bool downstreamSerialBufOverflow = false;

/*
===============================
     CORE ARDUINO FUNCTIONS
===============================
These are the two functions that Arduino calls automatically.
*/

// runs once
void setup() {
  bool hasUpstream = checkUpstream(); // raw GPIO read before serial init

  // === SERIAL INITIALIZATION ===
  Serial.begin(115200);
  UpstreamSerial.begin(115200, SERIAL_8N1, RX1, TX1);
  DownstreamSerial.begin(115200, SERIAL_8N1, RX2, TX2);

  LOGLN("\n========================================");
  LOGLN("    OPEN OCTAVE FIRMWARE V5 - INIT");
  LOGLN("========================================");

  // ===== VALIDATION =====
  LOG("[SETUP] Validating hardware config... ");
  if (!validateHardwareInit()) {
    LOGLN("[ERROR] CRITICAL: Hardware validation failed!");
    LOGLN("System halted. Check configuration.");
    while (true) {
      delay(1000);
    } // Halt - configuration error
  }
  LOGLN("OK");

  LOGLN("[SETUP] Loading default sequence... ");
  loadDefaultSequence();
  LOGF("OK (\"%s\", %d steps)\n", currentSequence.name, currentSequence.length);

  // ===== INITIALIZATION =====
  LOG("[SETUP] Configuring speaker... ");
  noteSetup();
  LOGF("OK\n");

  LOG("[SETUP] Initializing I2C... ");
  Wire.begin(21, 22);
  LOGLN("OK");

  LOG("[SETUP] Initializing expansion board... ");
  if (!ioport.begin()) {
    LOGLN("[ERROR] PCA9555 I/O expander not responding at address 0x20!");
    LOGLN("Check I2C wiring (SDA=21, SCL=22) and verify the chip is powered.");
  } else {
    LOGLN("OK");
  }

  LOG("[SETUP] Initializing servo driver... ");
  servoDriver.init();
  servoDriver.setFrequency(SERVO_FREQ);
  LOGF("OK (freq: %dHz)\n", SERVO_FREQ);

  LOG("[SETUP] Initializing LEDs... ");
  leds.begin();
  leds.setBrightness(LED_BRIGHTNESS);
  leds.show();
  LOGF("OK (%d LEDs initialized; brightness: %d)\n", NUM_KEYS, LED_BRIGHTNESS);

  // initialize each key
  LOGLN("[SETUP] Initializing keys:");
  for (int i = 0; i < NUM_KEYS; i++) {
    ioport.pinMode(keys[i].buttonPin, INPUT);
    servoRest(keys[i].servoChannel);
    keys[i].isPressed = false;

    LOGF("  Key %d: btn_pin=%d, led_idx=%d, servo_ch=%d, freq=%dHz\n", i,
         keys[i].buttonPin, keys[i].ledIndex, keys[i].servoChannel,
         keys[i].noteFreq);
  }
  LOGF("OK (%d keys initialized)\n", NUM_KEYS);

  LOGF("[SETUP] Configuring external button pins... ");
  ioport.pinMode(ON_OFF_PIN, INPUT);
  ioport.pinMode(GUIDED_SEQ_BUTTON_PIN, INPUT);
  ioport.pinMode(TEACHING_SEQ_BUTTON_PIN, INPUT);
  ioport.pinMode(RECORD_BUTTON_PIN, INPUT);
  LOGLN("OK");

  if (!hasUpstream){
    LOGLN("[SETUP] Connecting to WiFi...");
    connectToControllerBlocking();
    LOGLN("[SETUP] WiFi & WebSocket Active!");
  }

  LOGLN("========================================");
  LOGLN("[SETUP] Complete!");
  LOGLN("========================================\n");

  playStartupAnimation();

  if (isMaster) {
    sendHelloToController();
  }
}

// runs repeatedly forever
void loop() {
  ioport.pinStates();
  checkOnOffButton();

  if (isMaster){
    handleControllerConnection();
    handleControllerCommunication();
    checkWifiStatus();
  } else {
    // Slaves must drain the USB serial buffer to prevent overflow,
    // and must respond to the 'i' command with 'BYE' so the Node.js
    // controller knows to hide this serial port from the UI.
    while (Serial.available()) {
      char c = Serial.read();
      if (c == 'i') {
        LOGLN("BYE");
      }
    }
  }

  if (on){
    handleChainCommunication();

    if (isMaster){
      handleSequencePlayback();
      handleSequenceButtons();
      handleRecordButton();
    }

    handleKeyPresses();
  }

  // Audio now runs on its own FreeRTOS task, so the loop is no longer
  // throttled by i2s_write(). Yield for 1ms to avoid hammering the I2C
  // bus with thousands of ioport.pinStates() reads per second.
  vTaskDelay(1);
}

void checkOnOffButton(){
  if (millis() - lastOnOffSwitchTime >= BUTTON_DEBOUNCE_DELAY){
    // if on/off button pressed
    if (ioport.stateOfPin(ON_OFF_PIN) == HIGH){
      if (on) {
        powerOff();
      } else {
        powerOn();
      }
      lastOnOffSwitchTime = millis();
    }
  }
}

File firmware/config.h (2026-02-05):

#ifndef CONFIG_H
#define CONFIG_H

#include <Adafruit_NeoPixel.h>

#define SPEAKER_PIN 8
#define MODE_SWITCH_PIN 2

#define SERVO_FREQ 50
#define SERVO_REST_ANGLE 0
#define SERVO_PRESS_ANGLE 180

#define NUM_LEDS 10
#define NUM_KEYS 2
#define DEBOUNCE_DELAY 50
#define SEQUENCE_LENGTH 4

#define KEY0_BUTTON_PIN 3
#define KEY0_LED_PIN 5
#define KEY0_SERVO_CHANNEL 1
#define KEY0_NOTE 262

#define KEY1_BUTTON_PIN 4
#define KEY1_LED_PIN 6
#define KEY1_SERVO_CHANNEL 2
#define KEY1_NOTE 294

#define COLOR_RED 0xFF0000
#define COLOR_GREEN 0x00FF00
#define COLOR_BLUE 0x0000FF
#define COLOR_WHITE 0xFFFFFF

#define ledStick(pin) Adafruit_NeoPixel(NUM_LEDS, pin, NEO_GRB + NEO_KHZ800)
#define servoPull(channel) servoDriver.setAngle(channel, SERVO_PRESS_ANGLE)
#define servoRest(channel) servoDriver.setAngle(channel, SERVO_REST_ANGLE)
#define autoPressKey(keyIndex) servoPull(keys[keyIndex].servoChannel)
#define autoReleaseKey(keyIndex) servoRest(keys[keyIndex].servoChannel)

// ============ TYPE DEFINITIONS ============

enum Mode {
  MANUAL,         // no automatic functions, user plays manually
  AUTOMATIC_LEDS, // LEDs light up in sequence
  FULL_AUTOMATIC  // LEDs + servos play automatically
};

struct Key {
  int buttonPin;              // which Arduino pin the button is on
  Adafruit_NeoPixel ledStick; // controller for this key's LED stick
  int servoChannel;           // which channel on the PCA9685 motor driver (0-15)
  int noteFreq;
  bool isPressed;
};

struct SequenceStep {
  int keyIndex;
  int color;
  int duration;
};

// ============ FUNCTION PROTOTYPES ============

void checkModeSwitch();
void setMode(Mode mode);
void handleAutomaticModes();
void startSequence();
void stopSequence();
void executeSequenceStep(const SequenceStep &step);
void startKeyTone(int keyIndex);
void stopKeyTone(int keyIndex);
void checkButtons();
void lightUpKey(int keyIndex, int color);
void lightDownKey(int keyIndex);
void resetKey(int keyIndex);

#endif

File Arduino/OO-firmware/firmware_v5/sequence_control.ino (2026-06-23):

/*
===============================
       SEQUENCE HANDLING
===============================
*/

void handleSequenceButtons() {
  if (sequenceRunning || recording) return;

  // Suppress button triggers for 500ms after promotion to master.
  // The static debounce variables below don't update while the module is a
  // slave (handleSequenceButtons isn't called by slaves), so on the first
  // call after promotion, any held or bouncing button would register as a
  // rising edge and auto-start a sequence.
  if (millis() - promotionSuppressionTime < 500) return;

  static bool lastGuidedState = false;
  static bool lastTeachingState = false;

  bool guidedState = (ioport.stateOfPin(GUIDED_SEQ_BUTTON_PIN) == HIGH);
  bool teachingState = (ioport.stateOfPin(TEACHING_SEQ_BUTTON_PIN) == HIGH);

  if (guidedState && !lastGuidedState && millis() - lastSequenceButtonPressTime >= BUTTON_DEBOUNCE_DELAY) {
    startSequence(GUIDED);
    lastSequenceButtonPressTime = millis();
  } else if (teachingState && !lastTeachingState && millis() - lastSequenceButtonPressTime >= BUTTON_DEBOUNCE_DELAY) {
    startSequence(TEACHING);
    lastSequenceButtonPressTime = millis();
  }

  lastGuidedState = guidedState;
  lastTeachingState = teachingState;
}

// handles automatic sequence playback
void handleSequencePlayback() {
  if (!sequenceRunning || currentSequenceMode == BROADCAST)
    return;

  // Defensive check: ensure currentSequenceStep is valid
  if (currentSequenceStepIndex < 0 || currentSequenceStepIndex >= currentSequence.length) {
    LOGF("[ERROR] Invalid step index: %d encountered while handling automatic modes\n", currentSequenceStepIndex);
    testLogLogError(TESTLOG_INVALID_STEP_INDEX, F("ERROR_INVALID_STEP_INDEX"));
    stopSequence();
    return;
  }

  if (currentSequenceMode == TEACHING) {
    handleTeachingModePlayback();
  } else if (currentSequenceMode == GUIDED) {
    handleGuidedModePlayback();
  }
}

void handleTeachingModePlayback() {
  // If we're waiting for the servo to release (between consecutive same-key steps)
  if (waitingForServoRelease) {
    if (millis() - servoReleaseStartTime >= SERVO_RELEASE_DELAY) {
      waitingForServoRelease = false;
      executeCurrentSequenceStep();
    }
    return;
  }

  if (millis() - currentStepStartTime >= CURRENT_STEP.duration) {
    LOGF("[SEQ] Step %d/%d complete\n", currentSequenceStepIndex + 1, currentSequence.length);

    bool requiresServoDelay = false;

    for (int i = 0; i < CURRENT_STEP.numKeys; i++) {
      uint8_t keyIndex = CURRENT_STEP.keys[i];
      uint8_t moduleIndexForStep = keyIndex / NUM_KEYS;

      if (moduleIndexForStep > 0) {
        chainSendKeyCmd(DownstreamSerial, 'r', keyIndex);
      } else {
        resetKey(keyIndex);
      }

      int nextIndex = currentSequenceStepIndex + 1;
      if (nextIndex < currentSequence.length) {
        for (int j = 0; j < currentSequence.steps[nextIndex].numKeys; j++) {
          if (currentSequence.steps[nextIndex].keys[j] == keyIndex) {
            requiresServoDelay = true;
          }
        }
      }
    }

    currentSequenceStepIndex++;
    if (currentSequenceStepIndex >= currentSequence.length) {
      LOGLN("[SEQ] Sequence complete");
      stopSequence();
      return;
    }

    if (requiresServoDelay) {
      waitingForServoRelease = true;
      servoReleaseStartTime = millis();
    } else {
      executeCurrentSequenceStep();
    }
  }
}

void handleGuidedModePlayback() {
  bool allRequiredKeysPressed = true;
  unsigned long maxHoldStart = currentStepStartTime;

  // Check if all required keys are currently pressed and find the latest press time
  for (int i = 0; i < CURRENT_STEP.numKeys; i++) {
    uint8_t keyIndex = CURRENT_STEP.keys[i];

    if (!globalKeyIsPressed[keyIndex]) {
      allRequiredKeysPressed = false;
      break;
    }

    // Use the later of (key press time, step start time) so that holds
    // that began before the current step don't count toward its duration.
    unsigned long holdStart = globalKeyPressTime[keyIndex];
    if (holdStart < currentStepStartTime) {
      holdStart = currentStepStartTime;
    }

    // Keep track of the latest press time among all required keys
    if (holdStart > maxHoldStart) {
      maxHoldStart = holdStart;
    }
  }

  // Evaluate if all keys have been held for the required duration
  if (allRequiredKeysPressed && (millis() - maxHoldStart >= CURRENT_STEP.duration)) {
    LOGF("[SEQ] All correct keys pressed for step %d, advancing sequence.\n", currentSequenceStepIndex + 1);

    // Reset LEDs / send release commands for all keys in the current step
    for (int i = 0; i < CURRENT_STEP.numKeys; i++) {
      uint8_t keyIndex = CURRENT_STEP.keys[i];
      uint8_t moduleIndexForStep = keyIndex / NUM_KEYS;

      if (moduleIndexForStep > 0) {
        chainSendKeyCmd(DownstreamSerial, 'r', keyIndex);
      } else {
        resetKey(keyIndex);
      }
    }

    currentSequenceStepIndex++;
    if (currentSequenceStepIndex >= currentSequence.length) {
      LOGLN("[SEQ] Sequence complete");
      stopSequence();
      playSuccessAnimation();
      return;
    }

    delay(80); // delay to ensure visible LED relighting
    executeCurrentSequenceStep();
  }
}

// starts playing the sequence from the beginning
void startSequence(SequenceMode mode) {
  if (sequenceRunning) {
    LOGLN("[SEQ] Sequence already running, ignoring start request");
    return;
  }

  if (mode != BROADCAST && currentSequence.length <= 0) {
    LOGF("[ERROR] Invalid sequence length: %d encountered while starting sequence\n", currentSequence.length);
    return;
  }

  sequenceRunning = true;
  currentSequenceStepIndex = 0;
  currentStepStartTime = millis();
  currentSequenceMode = mode;

  LOGLN("\n[SEQ] ======== STARTING SEQUENCE ========");
  LOGF("[SEQ] Sequence: %s (%d steps)\n", currentSequence.name, currentSequence.length);
  LOGF("[SEQ] Mode: %s\n", getCurrentSequenceModeString());
  LOGLN("EVT sequence_started");
  emitStatus();

  if (testLogEnabled) {
    testLogExpectedNextStepStartTime = currentStepStartTime;
    testLogLastAutoKey = -1;
    testLogAutoRepeatStreak = 0;
  }

  // immediately play the first step (if not in broadcast mode)
  if (currentSequenceMode != BROADCAST) {
    executeCurrentSequenceStep();
  } else {
    char bCmd[16];
    snprintf(bCmd, sizeof(bCmd), "b%d\n", currentOctave);
    DownstreamSerial.write((uint8_t*)bCmd, strlen(bCmd));
  }
}
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

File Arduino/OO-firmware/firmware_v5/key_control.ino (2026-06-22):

/*
===============================
   KEYBOARD CONTROL FUNCTIONS
===============================
These handle button detection, sound playback, and LED control for the keys.
*/

// checks all buttons and plays/stops tones based on their state
void handleKeyPresses() {
  for (int i = 0; i < NUM_KEYS; i++) {
    int globalKey = (moduleChainIndex * NUM_KEYS) + i;
    bool buttonPressed = ioport.stateOfPin(keys[i].buttonPin) == HIGH;

    if (buttonPressed && !keys[i].isPressed) {

      // apply debouncing to avoid false triggers
      if (millis() - globalKeyPressTime[globalKey] >= BUTTON_DEBOUNCE_DELAY) {
        unsigned long pressDetectedMs = millis();

        // use local keys array to detect button press edges, and global array
        // for sequence handling.
        keys[i].isPressed = true;
        globalKeyIsPressed[globalKey] = true;
        globalKeyPressTime[globalKey] = pressDetectedMs;
        toneStartTime[i] = pressDetectedMs;  // Track when this tone started

        if (!isMaster) {
          chainSendKeyCmd(UpstreamSerial, 'K', globalKey);
        }

        LOGF("[KEY] Key %d PRESSED (pin %d, freq %dHz)\n", i, keys[i].buttonPin, keys[i].noteFreq);

        if (isMaster && recording) {
          recordKeyPress(globalKey);
        } else if (isMaster && sequenceRunning && currentSequenceMode == BROADCAST) {
          for (int m = 1; m < numModulesInChain; m++) {
            int slaveGlobalKey = (m * NUM_KEYS) + i;
            chainSendKeyCmdWithColor(DownstreamSerial, 't', slaveGlobalKey, getBrandGradientColor(i));
          }
        } else if (isMaster) {
          evaluateWrongKeyFeedback(globalKey, true);
        }

        unsigned long audioStartedMs = millis();
        testLogLogManualPress(i, pressDetectedMs, audioStartedMs);
      }

    } else if (!buttonPressed && keys[i].isPressed) {
      keys[i].isPressed = false;
      globalKeyIsPressed[globalKey] = false;

      if (!isMaster) {
        chainSendKeyCmd(UpstreamSerial, 'k', globalKey);
      }
      
      LOGF("[KEY] Key %d RELEASED\n", i);

      if (isMaster && recording) {
        recordKeyRelease(globalKey);
      } else if (isMaster && sequenceRunning && currentSequenceMode == BROADCAST) {
        for (int m = 1; m < numModulesInChain; m++) {
          int slaveGlobalKey = (m * NUM_KEYS) + i;
          chainSendKeyCmd(DownstreamSerial, 'r', slaveGlobalKey);
        }
      } else if (isMaster) {
        evaluateWrongKeyFeedback(globalKey, false);
      }
    }
  }
}

// lights up all LEDs on a key's LED strip with the specified color
void lightUpKey(int keyIndex, uint32_t color) {
  if (!isValidLocalKeyIndex(keyIndex)) {
    LOGF("[ERROR] Invalid keyIndex: %d encountered while turning on LEDs\n", keyIndex);
    return;
  }

  leds.setPixelColor(keys[keyIndex].ledIndex, color);
  leds.show();
  LOGF("[LED] Key %d LED ON: color=%s\n", keyIndex, getColorString(color));
}

// turns off all LEDs on a key's LED strip
void lightDownKey(int keyIndex) {
  if (!isValidLocalKeyIndex(keyIndex)) {
    LOGF("[ERROR] Invalid keyIndex: %d encountered while turning off LEDs\n", keyIndex);
    return;
  }

  leds.setPixelColor(keys[keyIndex].ledIndex, 0);
  leds.show();
  LOGF("[LED] Key %d OFF\n", keyIndex);
}

// resets a key to its default state (LED off, servo at rest)
// NOTE: We do NOT clear isPressed here. handleKeyPresses() tracks the physical
// button state and will detect the actual release when the servo lets go.
void resetKey(int keyIndex) {
  if (!isValidLocalKeyIndex(keyIndex)) {
    LOGF("[ERROR] Invalid keyIndex: %d encountered while resetting key\n", keyIndex);
    return;
  }

  lightDownKey(keyIndex);
  autoReleaseKey(keyIndex);
}

// ============ STARTUP / SHUTDOWN ANIMATION ============

// Plays a rainbow sweep from left to right when the keyboard powers on.
// Each key lights up with its brand gradient color in sequence, holds briefly, then all LEDs off.
void playStartupAnimation() {
  LOGLN("[ANIM] Playing startup animation");

  for (int i = 0; i < NUM_KEYS; i++) {
    leds.setPixelColor(keys[i].ledIndex, getBrandGradientColor(i));
    leds.show();
    delay(SWEEP_DELAY_PER_KEY);
  }

  delay(STARTUP_WHITE_HOLD);

  for (int i = 0; i < NUM_KEYS; i++) {
    leds.setPixelColor(keys[i].ledIndex, 0);
  }
  leds.show();

  LOGLN("[ANIM] Startup animation complete");
}

// Plays a rainbow sweep from right to left when the keyboard powers off.
// All keys light up with their brand gradient colors, hold briefly,
// then turn off one by one from right to left.
void playShutdownAnimation() {
  LOGLN("[ANIM] Playing shutdown animation");

  for (int i = 0; i < NUM_KEYS; i++) {
    leds.setPixelColor(keys[i].ledIndex, getBrandGradientColor(i));
  }
  leds.show();
  delay(SHUTDOWN_WHITE_HOLD);

  for (int i = NUM_KEYS - 1; i >= 0; i--) {
    leds.setPixelColor(keys[i].ledIndex, 0);
    leds.show();
    delay(SWEEP_DELAY_PER_KEY);
  }

  LOGLN("[ANIM] Shutdown animation complete");
}

// Plays a double-flash rainbow animation across all keys on all connected modules
void playSuccessAnimation() {
  LOGLN("[ANIM] Playing success animation");
  
  for (int flash = 0; flash < 2; flash++) {
    // Turn all LEDs ON with brand colors
    for (int i = 0; i < NUM_KEYS; i++) {
      uint32_t color = getBrandGradientColor(i);
      leds.setPixelColor(keys[i].ledIndex, color);
      
      if (isMaster) {
        for (int m = 1; m < numModulesInChain; m++) {
          int slaveGlobalKey = (m * NUM_KEYS) + i;
          chainSendKeyCmdWithColor(DownstreamSerial, 'g', slaveGlobalKey, color);
        }
      }
    }
    leds.show();
    delay(150);

    // Turn all LEDs OFF
    for (int i = 0; i < NUM_KEYS; i++) {
      leds.setPixelColor(keys[i].ledIndex, 0);
      
      if (isMaster) {
        for (int m = 1; m < numModulesInChain; m++) {
          int slaveGlobalKey = (m * NUM_KEYS) + i;
          chainSendKeyCmd(DownstreamSerial, 'r', slaveGlobalKey);
        }
      }
    }
    leds.show();
    delay(150);
  }

  LOGLN("[ANIM] Success animation complete");
}

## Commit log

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2026-02-05 Selective merge: improved mode switch debouncing, removed activeAudioKey tracking, fixed lightUpKey color type, added config.h
    [config.h]
2026-02-05 replace cstdint with stdint.h; arduino uses c-style headers
    [firmware_config.h]
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2026-02-05 feat: replace mode switch button with serial commands + more serial commands
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2026-02-09 fix: remove aggregate initialiazation of neopixel object, added pin field and pointer, now initialised in setup
2026-02-09 fix: swap pins for LEDs and buttons due to LED signal bleed
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2026-02-18 fix: proper usb port in proxy config
    [server.js]
2026-02-19 refactor: disable WebSerial for ESP32 migration
    WebSerial requires AsyncTCP/ESPAsyncWebServer which are incompatible
    with the synchronous WebServer used by the API endpoints. Disabled
    WebSerial includes, callbacks, and debug macro integration.
    Serial Monitor over USB remains fully functional for testing.
    WebSerial can be re-added after migrating to AsyncWebServer.
    Also fixes latent bug in LOGF_P where va_arg() was called twice
    per format specifier (once for Serial, once for WebSerial).
2026-02-19 feat: remap GPIO pins and validation for ESP32
    Remapped pin assignments from Arduino Uno numbering to ESP32-safe
    GPIOs. Old pins 6, 7, 8 are SPI flash lines on ESP32 and would
    crash the board. GPIO 3 is UART0 RX and would break Serial Monitor.
    New assignments:
    - SPEAKER_PIN: 8 -> 25 (DAC-capable)
    - KEY0: btn=4, led=16
    - KEY1: btn=5, led=17
    - KEY2: btn=18, led=19
    - Reserved GPIO 21/22 for I2C (PCA9685)
    Also updated validateHardwareInit() pin range checks from
    Uno range (2-8) to ESP32 range (0-39).
2026-02-19 feat: switch WiFi to Access Point mode
    ESP32 now creates its own 'Open Octave' WiFi network instead of
    joining an existing one. This is the correct mode for both
    classroom deployment and standalone testing - no external router
    needed. Updated handleWiFiStatus() to report AP client count
    instead of checking STA connection state.
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2026-02-19 feat: replace HTTP WebServer with WebSocket serial-over-WiFi interface
    - ESP32: replaced WebServer.h with WebSocketsServer.h (port 81)
    - ESP32: deleted all HTTP endpoint handlers (~190 lines)
    - ESP32: added webSocketEvent() handler routing to processSerialCommand()
    - ESP32: added wsBroadcastLog() for dual-output to Serial + WebSocket
    - Debug: modified all LOG macros to broadcast to WebSocket clients
    - Controller: replaced node-fetch with ws WebSocket client
    - Controller: unified WIFI and SERIAL into same fire-and-forget pattern
    - Controller: added automatic reconnection with exponential backoff
    - Controller: fixed stale mode names (auto_leds -> guided, full_auto -> teaching)
    [server.js]
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2026-02-24 add .clangd file to remove false errors in VScode related to Arduino toolchain
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2026-03-02 Sync PR fixes + local UI/server updates
    [server.js]
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2026-03-08 fix: prevent instant step skip when key is already held
    [sequence_control.ino]
2026-03-08 feat: added wrong-key feedback in guided mode
    [key_control.ino]
2026-03-08 refactor(controller): update command translation for firmware v5
    Firmware v5 removed the persistent mode system (m/a/f commands).
    Mode is now specified at sequence start time: g=guided, t=teaching.
    Commands remapped: test LEDs t→l, test servos u→s, view seq l→c,
    test log toggle g→q. Removed /api/modes endpoint and next/prev
    sequence commands which no longer exist in v5.
    [server.js]
2026-03-08 refactor(web): update UI controls for firmware v5 mode system
    Firmware v5 removed persistent modes (Manual/Guided/Teaching).
    Mode is now specified at sequence start time. Replaced the separate
    Mode card and Start/Stop/Next/Prev buttons with unified controls:
    - "Practice" / "Start Guided" (sends g command)
    - "Watch & Learn" / "Start Teaching" (sends t command)
    - "Stop" (sends x command)
    Removed Next/Prev buttons (commands removed in v5).
    Updated developer diagnostics labels (l→c for view sequence).
2026-03-08 fix(web): widen play controls grid so buttons fit on one line
    Changed grid from 3-column to 2-column layout (now only 2 cards:
    Play + Tests instead of 3). Set btn-row to nowrap so Practice,
    Watch & Learn, and Stop buttons stay on a single line.
2026-03-08 fix(web): hide Tests card in user mode
    LED and servo test controls are now developer-only.
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2026-03-09 feat: centralise brand colours in shared/colors.json
    Created software/shared/colors.json as the single source of truth
    for the Open Octave brand colour palette (finger-to-colour mapping).
    Both controller and frontend now import from this file.
    Brand gradient: Cyan → Green → Gold → Coral → Magenta
    Thumb=00B4D8, Index=4ECB71, Middle=FFD700, Ring=FF6B35, Pinky=E8368F
    Red (FF0000) is reserved exclusively for wrong-key feedback in
    guided mode and is not an allowed sequence colour.
    Changes:
    - software/shared/colors.json: finger colours, key-to-finger maps
    - controller/server.js: import shared colours, replace inline map,
    add GET /api/colors endpoint
    - controller/database/sqlite.js: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
    [helpers.ino, sequence_control.ino, server.js]
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2026-03-09 replace colours column in user mode squence info table with finger names column
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2026-03-09 fix(controller): always regenerate upload lines to apply CB remapping
    Previously, cached uploadLines would bypass the colourblind palette
    remapping in generateUploadLinesFromData(). Now upload lines are
    always regenerated from data.steps so runtime options like colorMode
    are applied consistently.
    [server.js]
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2026-03-09 fix stale references to getCurrentModeString in testlogging.ino
    [testlogging.ino]
2026-03-09 fix: added missing serial initialisation
    [firmware_v5.ino]
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2026-03-10 fix: conditionally set up WiFi only for master modules
    [command_handling.ino, firmware_v5.ino, helpers.ino]
2026-03-10 fix: fixed issue where last module in chain never updates the total module count
    [command_handling.ino]
2026-03-10 fixed stale references to old function names
    [command_handling.ino]
2026-03-10 fix: fixed stale count for total modules when modules are removed by adding new timeout check fo heartbeat replies. Also added new function which wraps the chain communication function calls.
    [command_handling.ino, firmware_v5.ino]
2026-03-11 fix: added missing connectToWebsocket() call
    [firmware_v5.ino]
2026-03-12 fix: remove unused _intsup.h include
    [firmware_v5.ino]
2026-03-12 fix: allowed downstream modules to respond to sequence stop commands
    [communication.ino, sequence_control.ino]
2026-03-12 fix: allowed for wrong key press feedback across all modules during guided playback
    [communication.ino, key_control.ino, sequence_control.ino]
2026-03-12 refactored inefficient module number parsing and replaced with calculation
    [communication.ino, sequence_control.ino]
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2026-03-12 fix(communication): explicitly handle heartbeat bytes during command string accumulation to prevent data loss
    [communication.ino]
2026-03-12 fix: separated local and global key index validation
    [helpers.ino, key_control.ino, sequence_control.ino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]
2026-03-12 fix: refactored inconsistent unsigned long type for globalKey variable; changed to int
    [key_control.ino]
2026-03-12 fix: removed unused moduleIndex param from forwardNextStepAlongChain
    [sequence_control.ino]
2026-03-12 fix: stopped slave modules from accepting sequence upload commands
    [communication.ino]
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2026-03-13 fix: fixed logic for conditional servo delay for chords
    [sequence_control.ino]
2026-03-13 fix: removed stale argument in forwardNextStepAlongChain() call
    [sequence_control.ino]
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2026-03-16 fix: added state tracking to on/off debouncing
    [firmware_v5.ino]
2026-03-16 fix: added sequence button safety (debounce state tracking + sequenceRunning guard clause)
    [firmware_v5.ino, sequence_control.ino]
2026-03-16 feat: add record-to-sequence via physical button (pin 15)
    Pressing the record button on PCA9555 pin 15 toggles recording mode.
    While recording, key presses are captured as sequence steps with hold
    durations. Keys pressed within 40ms of each other are grouped as chord
    steps. Recording auto-stops at MAX_SEQUENCE_LENGTH (64). The recorded
    sequence replaces currentSequence for immediate playback. A white flash
    signals recording start/stop.
    [firmware_v5.ino, key_control.ino, record_control.ino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]
2026-03-16 fix: remove unused recChordKeyHeld array
    The array was written to but never read — the implementation commits
    on first key release, so per-key held tracking is unnecessary.
    [firmware_v5.ino, record_control.ino]
2026-03-16 fix: correctly configure pins for external buttons as INPUT
    [firmware_v5.ino]
2026-03-16 fix: correctly configure RECORD_BUTTON_PIN as INPUT
    [firmware_v5.ino]
2026-03-16 fix(record): prevent sequence upload overlapping with sequence recording
    [communication.ino, record_control.ino]
2026-03-16 fix(record): refactor sequence recording for multi-module support
    [communication.ino, key_control.ino, record_control.ino]
2026-03-16 refactor(controller): convert to WS server with multi-module support
    - Replace outbound WS client with inbound WS server on port 81
    - Add module registry (Map keyed by IP) with HELLO protocol handling
    - Add sendToModule/broadcastToAll command routing
    - Add new REST endpoints: GET /api/modules, POST /api/modules/:ip/upload,
    POST /api/modules/:ip/control, POST /api/modules/all/upload,
    POST /api/modules/all/control, DELETE /api/db/sequences/:id
    - Update sequence data format: {k,c,d} -> {keys[],colors[],duration}
    - Add auto-migration for old format sequences on startup
    - Update upload line generation for firmware v5 protocol (dot-separated
    keys/colors, s= step count in U line)
    - Add maxKey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
    [server.js]
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2026-03-16 feat(firmware): add HELLO protocol for controller registration
    Send HELLO modules=<N> to the controller WebSocket server:
    - On initial WS connection (in webSocketEvent WStype_CONNECTED handler)
    - When chain count increases (downstream heartbeat reports more modules)
    - When chain count decreases (downstream heartbeat timeout)
    The controller uses this to populate its module registry with the
    correct chain length and total key count per connected master.
    When a slave promotes to master, HELLO is sent automatically via the
    existing WStype_CONNECTED callback after WiFi/WS reconnection.
    [communication.ino, wifi.ino]
2026-03-16 fix: removed duplicated F() calls for log strings
    [key_control.ino]
2026-03-16 fix: fixed dodgy debounce logic for on/off control
    [firmware_v5.ino]
2026-03-16 fix: stop sequences on system shutdown
    [firmware_v5.ino]
2026-03-16 fix: added noTone() to stopSequence() to stop key tones from persisting on system shutdown during sequence playback
    [sequence_control.ino]
2026-03-16 fix: removed more duplicate F() calls
    [record_control.ino]
2026-03-17 fix(controller): handle led_test and servo_test commands in module control endpoints
    The /api/modules/:ip/control and /api/modules/all/control endpoints only
    accepted 'start' and 'stop', causing the UI's Test LEDs/Servos buttons
    to return 400 errors. Now maps led_test -> 'l' and servo_test -> 's'.
    [server.js]
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2026-03-22 fix: ensure firmware still listens for on/off commands from controller while off; fixes issue where the software cannot turn module back on after turning them off
    [communication.ino, firmware_v5.ino]
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2026-03-23 fix: added missing handleWifiConnection() call in main loop
    [firmware_v5.ino]
2026-03-23 fix: added missing semicolon
    [wifi.ino]
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2026-03-24 refactored on/off handlig logic. Firmware no longer accepts power toggles from software, and does not listen for software commands while off. Removed 'o' case from processSingleCharCommands and start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
    [communication.ino, helpers.ino]
2026-03-24 fix: added on/off guard in handleUsbSerialCommands
    [communication.ino]
2026-03-24 fix: updated chord code
    [chord_synthesis.ino]
2026-03-24 temp fix for demo 3 server.js & app.jsx
    [server.js]
2026-03-24 fix: removed more old audio functionality
    [firmware_v5.ino, key_control.ino, sequence_control.ino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]
2026-03-25 fix: stop recordings and playback when promoting or demoting modules
    [master_control.ino, slave_control.ino]
2026-03-25 fix: move audio synthesis to dedicated FreeRTOS task to prevent WiFi blocking
    [chord_synthesis.ino, firmware_v5.ino]
2026-03-26 feat(controller): multi-serial port support with WS shim
    Replace the single port/parser globals with a serialPorts Map. Each
    serial port gets a WebSocket-like shim so sendToModule() and
    broadcastToAll() work uniformly across USB serial and WiFi transports.
    Key changes:
    - SERIAL_PORTS env var (comma-separated) with SERIAL_PORT fallback
    - Serial modules registered in the modules Map with transport='serial'
    - BYE message handling: sets connected=false, pauses communication
    - HELLO re-activates a BYE'd module (master promotion)
    - Auto-connects configured serial ports on server startup
    - cleanupStaleModules and ping loop skip serial shims
    - Removed uploadLinesToSerial (serial modules use the uni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
    [server.js]
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2026-03-31 feat(controller): auto-reconnect serial ports after USB unplug/replug
    Add a 5-second interval that checks if any configured SERIAL_PATHS are
    missing from the active serialPorts map and attempts to reconnect them.
    This handles the case where a USB cable is unplugged and replugged
    without needing a server restart.
    [server.js]
2026-03-31 fix(firmware): validate heartbeat indices and flush buffers on role transitions
    - Reject heartbeat chain indices >= MAX_MODULES (prevents 255-module ghost
    chains caused by UART noise during physical cable connection/disconnection)
    - Flush upstream/downstream serial buffers and reset line-buffer state in
    both demoteToSlave() and promoteToMaster() to prevent stale noise bytes
    from being mis-parsed as heartbeats or commands
    - Reset heartbeat timers on promotion to prevent premature downstream
    timeout during chain stabilization
    - Send HELLO over USB serial in promoteToMaster() so the controller knows
    the module is back as master (was previously BYE'd as slave)
    [communication.ino, master_control.ino, slave_control.ino]
2026-03-31 fix(controller): use deterministic serial module keys and clean up stale entries
    - Use port-path based module keys (serial:/dev/cu.usbserial-120) instead
    of monotonically incrementing counter (serial:0, serial:1, ...) so that
    reconnecting the same USB cable reuses the same module entry rather than
    creating phantom ghosts in the modules Map
    - Clean up fully disconnected (BYE'd) module entries from the modules Map
    after the stale timeout, preventing them from accumulating indefinitely
    - Removes serialKeyCounter global as it is no longer needed
    [server.js]
2026-03-31 fix(firmware): delay HELLO until after startup animation for heartbeat stabilization
    Move sendHelloToController() to after playStartupAnimation() and gate it
    behind isMaster check. This gives the heartbeat protocol ~1.5s to
    stabilize after boot, so a slave module that receives an upstream
    heartbeat during startup will correctly demote to slave (and send BYE)
    rather than briefly announcing itself as an independent master.
    [firmware_v5.ino]
2026-03-31 fix(controller): re-register modules that send HELLO after being cleaned up
    When a module sends HELLO but its entry was previously deleted from the
    modules Map (e.g. by stale cleanup after BYE), the handler now re-creates
    the entry with a fresh registerModule call instead of silently ignoring
    the message. This makes the controller resilient regardless of cleanup
    timing.
    [server.js]
2026-03-31 fix(firmware): prevent auto-play of default sequence on promotion to master
    handleSequenceButtons() uses static variables (lastGuidedState,
    lastTeachingState) for edge detection, but these don't update while the
    module is a slave (the function is gated behind isMaster in loop()).
    On the first call after promotion, any held or bouncing button registers
    as a rising edge and immediately starts the default sequence.
    Fix: add a 500ms promotion suppression window in handleSequenceButtons()
    that skips all button processing right after promoteToMaster(). Also
    reset the regular debounce timer to prevent the 50ms window from passing
    on stale timestamps.
    [firmware_v5.ino, master_control.ino, sequence_control.ino]
2026-03-31 feat(seeds): replace demo sequences with recognisable melodies
    Replaced the seed preset library:
    - 3-key test patterns: kept Ping Pong, Up and Down, Quick Repeat (ids 0-2)
    - 1-octave melodies (ids 3-10): Mary Had a Little Lamb, Twinkle Twinkle,
    Happy Birthday, Ode to Joy, Jingle Bells, Hot Cross Buns,
    When The Saints, C Major Scale
    - 2-octave melodies (ids 11-19): Two Octave Scale, Fur Elise,
    Canon in D, Greensleeves, Amazing Grace, Twinkle Twinkle (2 Oct),
    Ode to Joy (2 Oct), Octave Jump Drill, Cross Octave Chords
    Added named note constants (C4-B5 including sharps) and a shorthand
    colour helper for cleaner sequence authoring.
    [server.js]
2026-03-31 fix(seeds): bump 250ms durations to 300ms for firmware compatibility
    Firmware rejects steps with duration < MIN_STEP_DURATION (300ms).
    Ode to Joy and Ode to Joy (2 Oct) had 750/250ms note pairs for the
    dotted-quarter-eighth rhythm. Changed to 700/300ms to stay within
    firmware limits while preserving the rhythmic feel.
    [server.js]
2026-03-31 fix: enforce 300ms minimum step duration across editor and API
    - Frontend: update validation threshold from 100ms to 300ms and set
    the duration input min attribute to 300
    - Backend: add per-step validation to POST /api/db/sequences endpoint
    enforcing firmware limits (duration 300-10000ms, max 4 keys/step,
    max 128 steps per sequence)
    This matches the firmware MIN_STEP_DURATION constraint and prevents
    sequences from being saved that would fail to upload.
    [server.js]
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2026-03-31 feat(midi): add Discard button to MIDI import result
    Reverted to the original auto-save import flow where clicking
    'Import MIDI' immediately parses and saves the sequence. Added a
    'Discard' button alongside 'Open in Editor' in the result view
    that deletes the saved sequence from the database if the user
    doesn't want to keep it.
    [server.js]
2026-03-31 feat(midi): defer saving until user accepts import result
    MIDI import now works as a two-step flow:
    1. 'Import MIDI' parses the file and shows a preview (nothing saved)
    2. User reviews metadata and clicks 'Accept' to save or 'Discard'
    to reset the upload window
    Backend: POST /api/midi/import now returns parsed sequence data
    without saving. Frontend saves via POST /api/db/sequences on accept.
    After saving, the result view transitions to show 'Open in Editor'
    and 'Dismiss' buttons.
    [server.js]
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2026-06-18 fix(audio): resolve zipper noise and volume jumps in synthesis
    Move envelope calculation to per-sample inner loop to prevent zipper noise
    Use a fixed max polyphony divisor for volume scaling instead of active notes to prevent sudden volume jumps
    [chord_synthesis.ino]
2026-06-18 refactor(server): replace _isSerialShim duck-typing with explicit transport checks
    Removes the hacky `_isSerialShim` property from the WebSocket shim object
    and replaces all usages with clean `entry.transport === 'serial'` checks
    against the module registry entry.
    [server.js]
2026-06-18 fix(server): restore testability lifecycle methods
    Restores the startServers(), stopServers(), and module.exports pattern
    that was removed in the usb branch. This allows tests to cleanly boot
    and tear down the server without port conflicts. Also updates tests to
    expect the new multi-serial transport architecture.
    [server.js]
2026-06-18 refactor(server): convert serial reconnect to event-driven loop
    Replaces the global 5-second polling interval for missing serial ports
    with a targeted, event-driven `scheduleSerialReconnect` function that
    triggers when a port closes or fails to open.
    [server.js]
2026-06-18 fix(server): abort sequence upload when serial port disconnects
    Updates the WS shim's readyState when the underlying serial port closes
    so that sendToModule correctly detects the disconnect and aborts the
    upload loop, instead of silently swallowing the error and continuing.
    [server.js]
2026-06-18 feat(server): implement USB serial auto-discovery
    Replaces the manual SERIAL_PATHS environment configuration with a robust
    auto-discovery mechanism that scans `SerialPort.list()` every 3 seconds
    to automatically connect and register actual USB devices without
    restarts.
    [server.js]
2026-06-18 fix(sequences): add duration bounds checking and async serial delay to sequence uplaod flow to prevent hardware buffer overflows
    [server.js]
2026-06-18 fix: correctly emit and display sequence running state tags
    [sequence_control.ino]
2026-06-18 fix(UI): display error message for failed sequence upload
    [server.js]
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2026-06-19 fix: resolve broadcast routing to guided mode and remove global broadcast button
    [server.js]
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2026-06-19 feat: reset octave offset during broadcast mode
    [communication.ino, sequence_control.ino, slave_control.ino]
2026-06-19 fix(uart): stabilize serial command parsing and handle broadcast disconnects
    [communication.ino]
2026-06-19 fix(chain): prevent immediate heartbeat timeout after demoteToSlave
    [slave_control.ino]
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2026-06-22 fix: sync connection state on startup
    [communication.ino, server.js]
2026-06-22 fix: ensure slave sends BYE on info request from controller
    [communication.ino, firmware_v5.ino]
2026-06-22 feat(audio): replace KS noise excitation with clavinet triangle/saw mix
    [chord_synthesis.ino]
2026-06-22 fix(audio): reduce KS chord clipping distortion and sawtooth buzz
    [chord_synthesis.ino]
2026-06-22 fix(audio): dial back KS volume multiplier to balance loudness with overdrive distortion
    [chord_synthesis.ino]
2026-06-23 chore(doc): fix stale comment
    [chord_synthesis.ino]
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2026-06-23 fix: route synth mode commands correctly in handleUsbSerialCommands
    [communication.ino]
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2026-06-23 fix: resolve synth mode serial bugs for slaves
    [communication.ino]
2026-06-23 fix(firmware): resolve auto-relative octave calculation and serial argument evaluation bugs
    [communication.ino, firmware_v5.ino, master_control.ino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]
2026-06-23 refactor(firmware,software): simplify octave config to master-only control
    - Remove per-module manual octave overrides (currentOctave, upstreamEffectiveOctaveCache)
    - Introduce chainBaseOctave: master's octave, passed through heartbeat unchanged
    - Slaves derive octave as chainBaseOctave + moduleChainIndex (capped at 7)
    - Simplify command format from p<module>.<octave> to p<octave>
    - Remove 'p' handler from slave upstream command parser
    - UI dropdown now only shown on master module
    - API endpoint no longer requires moduleIndex parameter
    [communication.ino, firmware_v5.ino, master_control.ino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]
2026-06-23 fix: update incorrect length checking for octave command processing
    [communication.ino]
